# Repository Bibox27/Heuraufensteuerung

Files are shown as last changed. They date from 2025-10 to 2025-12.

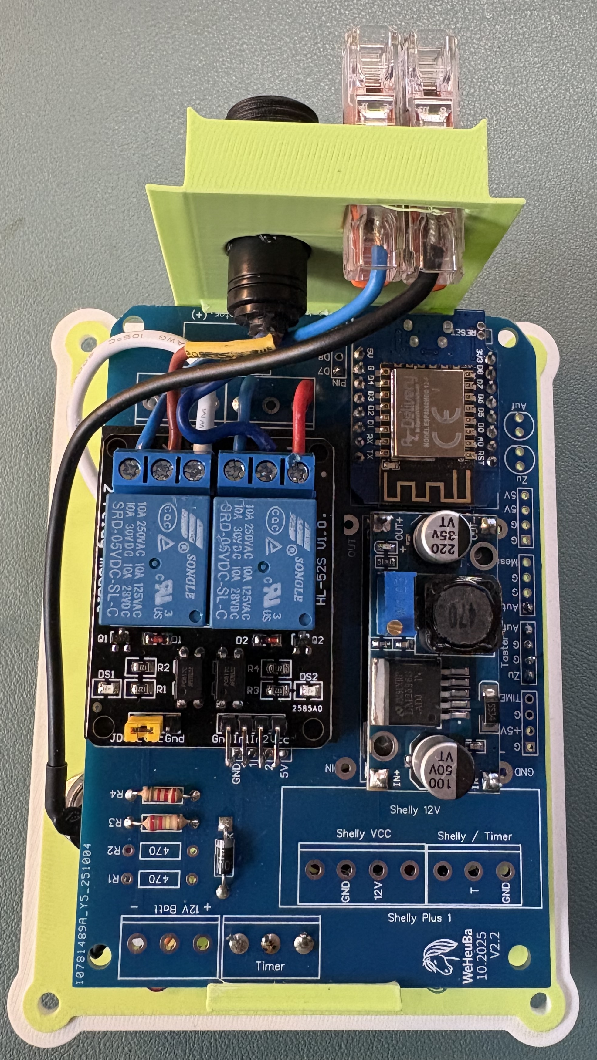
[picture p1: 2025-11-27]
Photos/IMG_0734.jpeg

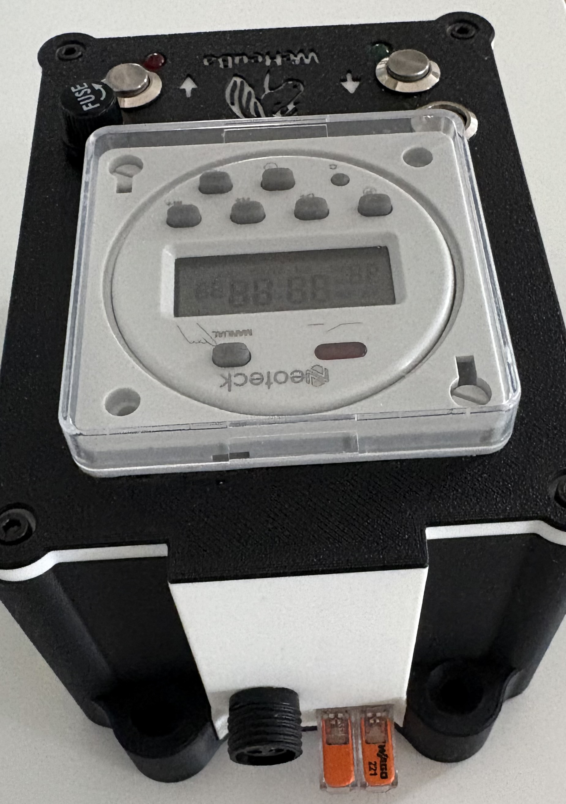
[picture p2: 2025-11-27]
Photos/IMG_0775.jpeg

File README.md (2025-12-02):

# Heuraufensteuerung
12V basierte Steuerung zum automatischen zeitabhängigem Öffnen und Schließen von Heuraufen

Bedienungsanleitung – ganz einfach erklärt
1. Grundprinzip
Die Steuerung bewegt einen Motor (12V DC) um eine Heuraufe zu öffnen oder zu schließen:
•	Öffnen (grüne LED)
•	Schließen (rote LED)
•	Entweder automatisch über die Zeitschaltuhr
•	Oder von Hand über die Taster
Die Fahrzeiten für Öffnen und Schließen sind fest einstellbar (webinterface)
 
2. Verhalten beim Einschalten (anlegen der 12V an die Steuerung)
Nach dem Start zeigt die Steuerung kurz:
1.	Grün leuchtet
2.	Rot leuchtet
Danach:
•	Wenn Auto-Modus AUS ist:
→ die rote LED blinkt (Hinweis: „Handbetrieb aktiv“)
 
3. Auto-Modus oder Handbetrieb
Auto-Modus EIN
•	Die rote LED blinkt nicht mehr
•	Die Zeitschaltuhr darf die Heuraufe automatisch bewegen
Handbetrieb
•	Rote LED blinkt dauerhaft
•	Die Zeitschaltuhr steuert NICHT, sie zeigt nur grün blinkend ein Signal an, wenn sie öffnen würde
•	Bewegen kann man nur über die beiden Taster
 
4. Taster „Auf“ (Öffnen)
Einfach drücken und halten
•	Motor fährt solange du drückst
•	Grüne LED leuchtet
•	Beim Loslassen → Motor stoppt sofort
Doppel-Klick (langsamer drücken als bei der Maus am Rechner)
•	Heuraufe öffnet komplett
•	Grüne LED leuchtet dabei
•	Danach stoppt alles wieder selbst
 
5. Taster „Zu“ (Schließen)
Einfach drücken und halten
•	Motor fährt solange du drückst
•	Rote LED leuchtet
•	Beim Loslassen → Motor stoppt sofort
Doppel-Klick (langsamer drücken als bei der Maus am Rechner)
•	Heuraufe schließt komplett
•	Rote LED leuchtet dabei
•	Danach stoppt alles wieder selbst
 
6. Zeitschaltuhr (Timer)
Der Timer kommt z. B. von einer Zeitschaltuhr oder einem Shelly Plus 1 12V (nicht installiert)
Wenn der Timer „an“ ist:
•	Die grüne LED blinkt
Im Auto-Modus zusätzlich:
•	Timer an → Die Heuraufe öffnet automatisch
•	Timer aus → Die Heuraufe schließt automatisch
Im Handbetrieb:
•	Die grüne LED blinkt nur als Anzeige
•	Die Heuraufe bewegt sich nicht automatisch
 
7. LED-Anzeigen – schnell erklärt
Grüne LED
•	Leuchtet: Die Heuraufe fährt auf
•	Blinkt: Timer aktiv
Rote LED
•	Leuchtet: Die Heuraufe fährt zu
•	Blinkt: Auto-Modus aus → Handbetrieb

Übersichtskarte – 6 Fresszeiten für deine Zeitschaltuhr
(ON = Öffnen / OFF = Schließen)

🕒 1. Beispiel-Fresszeiten 
Diese Zeiten sind alltagstauglich und orientieren sich an deinem Wunschstart um 06:00.
Fresszeit	Öffnen (ON)	Schließen (OFF)
1	06:00	07:00
2	10:00	11:00
3	13:00	14:00
… bis 20 Zeiten (meist reichen 5-6)
passe es genau an deinen Stall-Rhythmus an.
 
📘 2. Schritt-für-Schritt Anleitung zum Programmieren
🔧 A. Uhrzeit einstellen
1.	CLOCK gedrückt halten
2.	Währenddessen:
o	D+ = Wochentag
o	H+ = Stunde
o	M+ = Minute
3.	CLOCK loslassen → gespeichert
 
🟦 B. Schaltzeiten programmieren
Du programmierst immer ein Paar:
ON1 → OFF1, dann ON2 → OFF2 … bis ON6 → OFF6
 
🥇 Fresszeit 1 programmieren (06:00 – 07:00)
➤ ON1: Öffnen
1.	P drücken → Display zeigt 1 ON
2.	Wochentage mit D+ auswählen (am besten MO–SO)
3.	H+ → 06 einstellen
4.	M+ → 00 einstellen
➤ OFF1: Schließen
1.	P drücken → Display zeigt 1 OFF
2.	H+ → 07
3.	M+ → 00
 
🥈 Fresszeit 2 programmieren (10:00 – 11:00)
➤ ON2
•	P drücken, bis 2 ON erscheint
•	10:00 einstellen
➤ OFF2
•	P drücken, bis 2 OFF erscheint
•	11:00 einstellen
 
🥉 Fresszeit 3 programmieren (13:00 – 14:00)
➤ ON3
•	3 ON → 13:00
➤ OFF3
•	3 OFF → 14:00
 
🟩 Fresszeit 4 …
 
🔁 3. Wichtig: Betriebsmodus einstellen
Oben rechts der Schalter:
•	AUTO → das Programm läuft automatisch (muss aktiv sein)
•	ON → dauerhaft EIN
•	OFF → dauerhaft AUS
👉 Für die Heuraufe immer AUTO verwenden!

Technischer Hinweis:
Bei der beschriebenen Heuraufensteuerung handelt es sich um ein individuelles DIY-Projekt. Der Nachbau erfolgt vollständig auf eigene Verantwortung. Alle mechanischen, elektrischen und softwareseitigen Komponenten müssen vor Inbetriebnahme eigenständig geprüft, korrekt dimensioniert und sicher installiert werden. Für Schäden, Fehlfunktionen oder Risiken, die aus dem Nachbau oder unsachgemäßer Nutzung entstehen könnten, wird keinerlei Haftung übernommen. Jede Anpassung oder Erweiterung sollte nur mit entsprechendem Fachwissen durchgeführt werden.

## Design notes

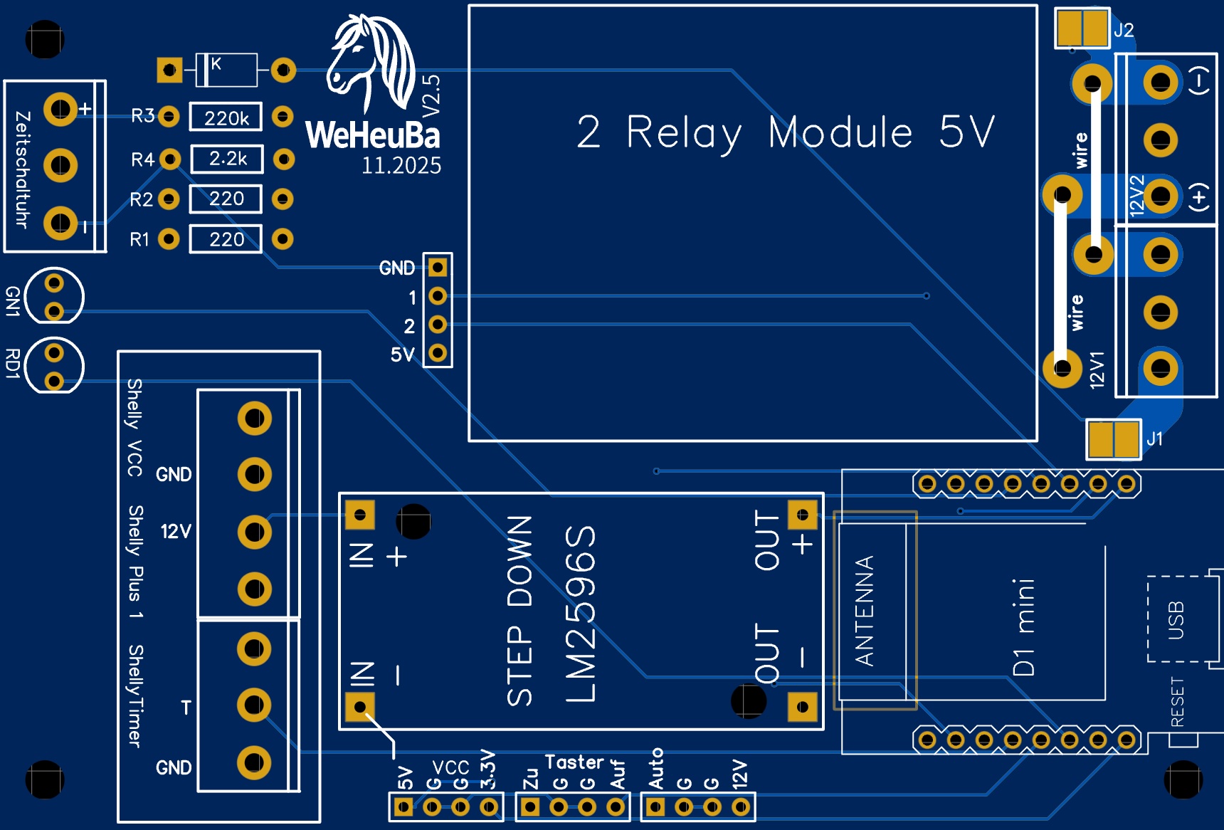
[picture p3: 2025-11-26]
Schematic/PCB Layout.jpg

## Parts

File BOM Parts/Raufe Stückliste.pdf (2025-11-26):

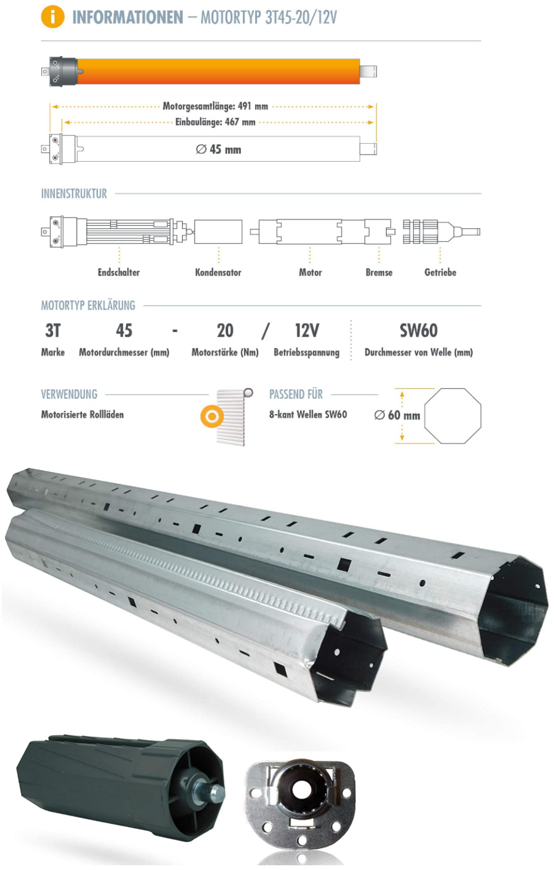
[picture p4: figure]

# Jalousiemotor mit Welle und Gurtscheiben

Preise auf Amazon (Februar 2023)
- 3T Rolladenmotor 12V 20Nm (40kg Zugkraft) | 100,90 €
- Achtkantwelle SW 60 150-170cm inkl. Lager | 26,90 €
- Gurtscheiben 4 x | 10,00 €
- Paracourt Seil 30m | 10,95 €
- Alurohr 4 x (20mm x 2 mm 2000mm lang) | 48,60 €
- Rohrverbinder (3D Drucker) habe ich auf thingivers.com hochgeladen
- Kabelbinder
- Windschutznetz | 22,95 €
- Umlenkrollen | 21,99 €
_______________________________________________________
| 242,29 €

# Automatische Heuraufe – Netz

Außenliegendes Gestänge, dass an den Raufenstützen hochgezogen wird. Das Netz rafft sich nach oben hin zusammen. Das Raffen kommt zustande indem das Paraourt Seil in 15 - 20 cm Abständen durch das Netz gezogen wird. Wer möchte kann mit Umlenkrollen alle vier Seiten mit dem Seil verbinden. Das hat den Vorteil, dass das Gestänge auch noch hochgezogen wird wenn ein Rohr aus den Eckenverbinden rausgezogen wurde (Pferd, Wind zerren daran).

Stand: Februar 2023

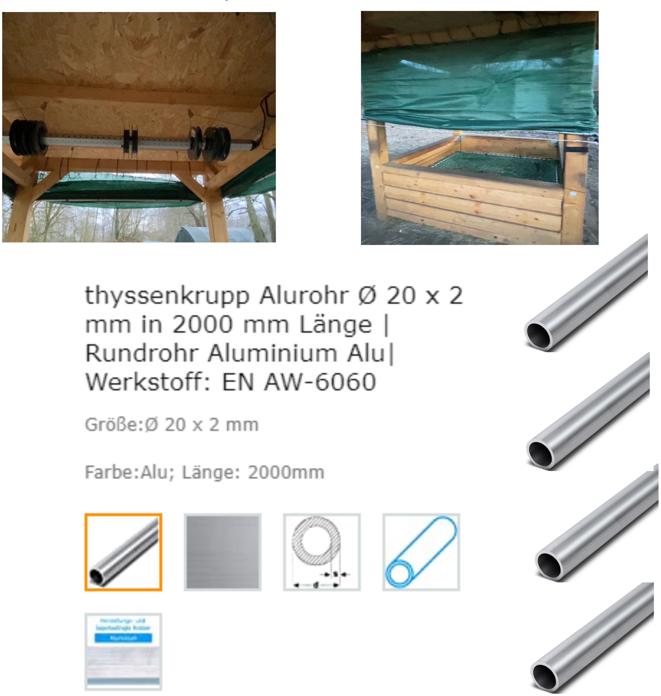
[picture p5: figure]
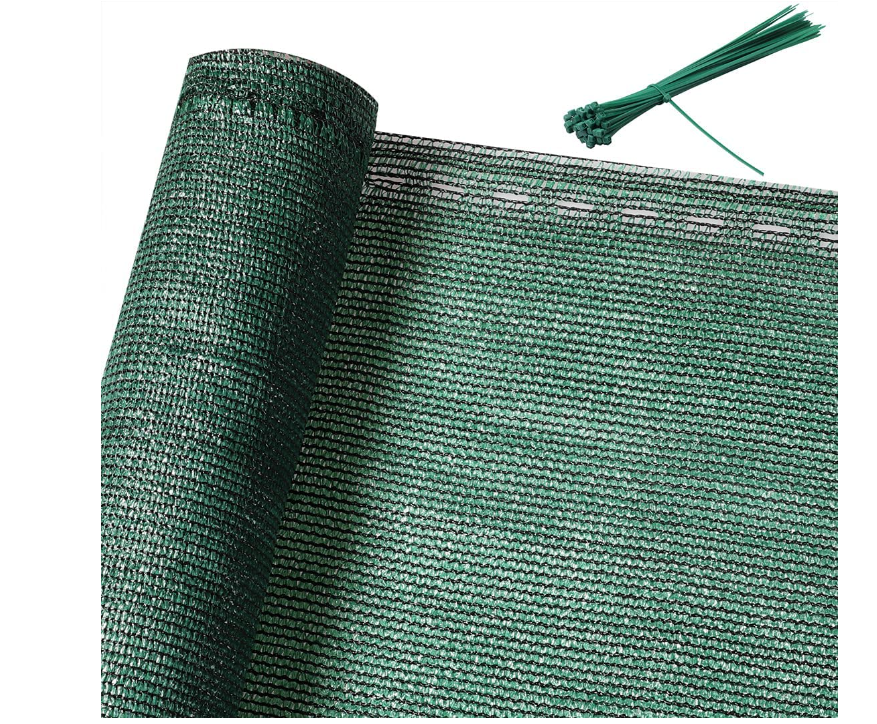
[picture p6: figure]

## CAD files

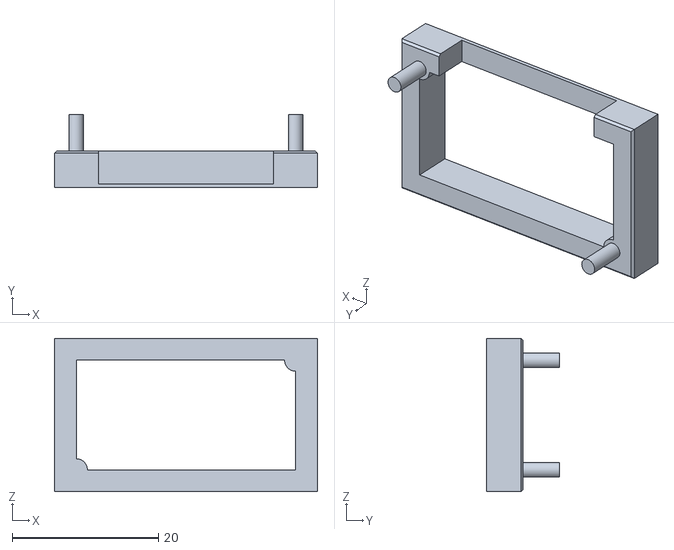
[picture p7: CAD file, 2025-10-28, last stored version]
LM2596_Halterung.stl
36.0 x 10.0 x 21.0

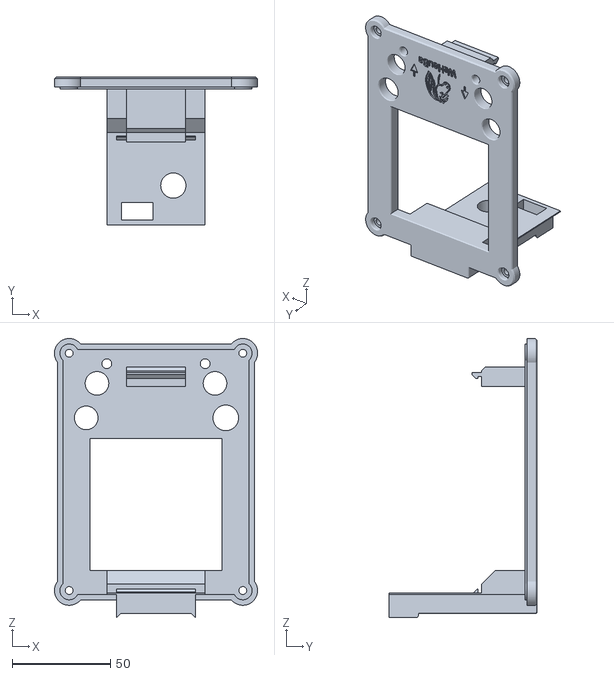
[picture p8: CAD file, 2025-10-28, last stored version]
WeHeuBa_Top (1).stl
103.3 x 75.0 x 141.8

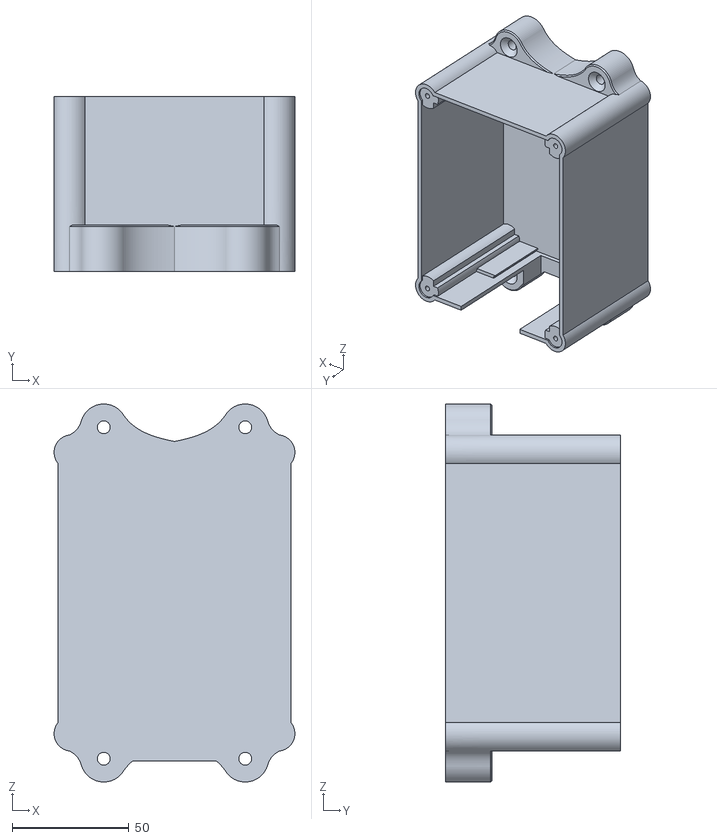
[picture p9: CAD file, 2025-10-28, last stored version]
WeHeuBa_Botton.stl
103.3 x 75.0 x 162.1

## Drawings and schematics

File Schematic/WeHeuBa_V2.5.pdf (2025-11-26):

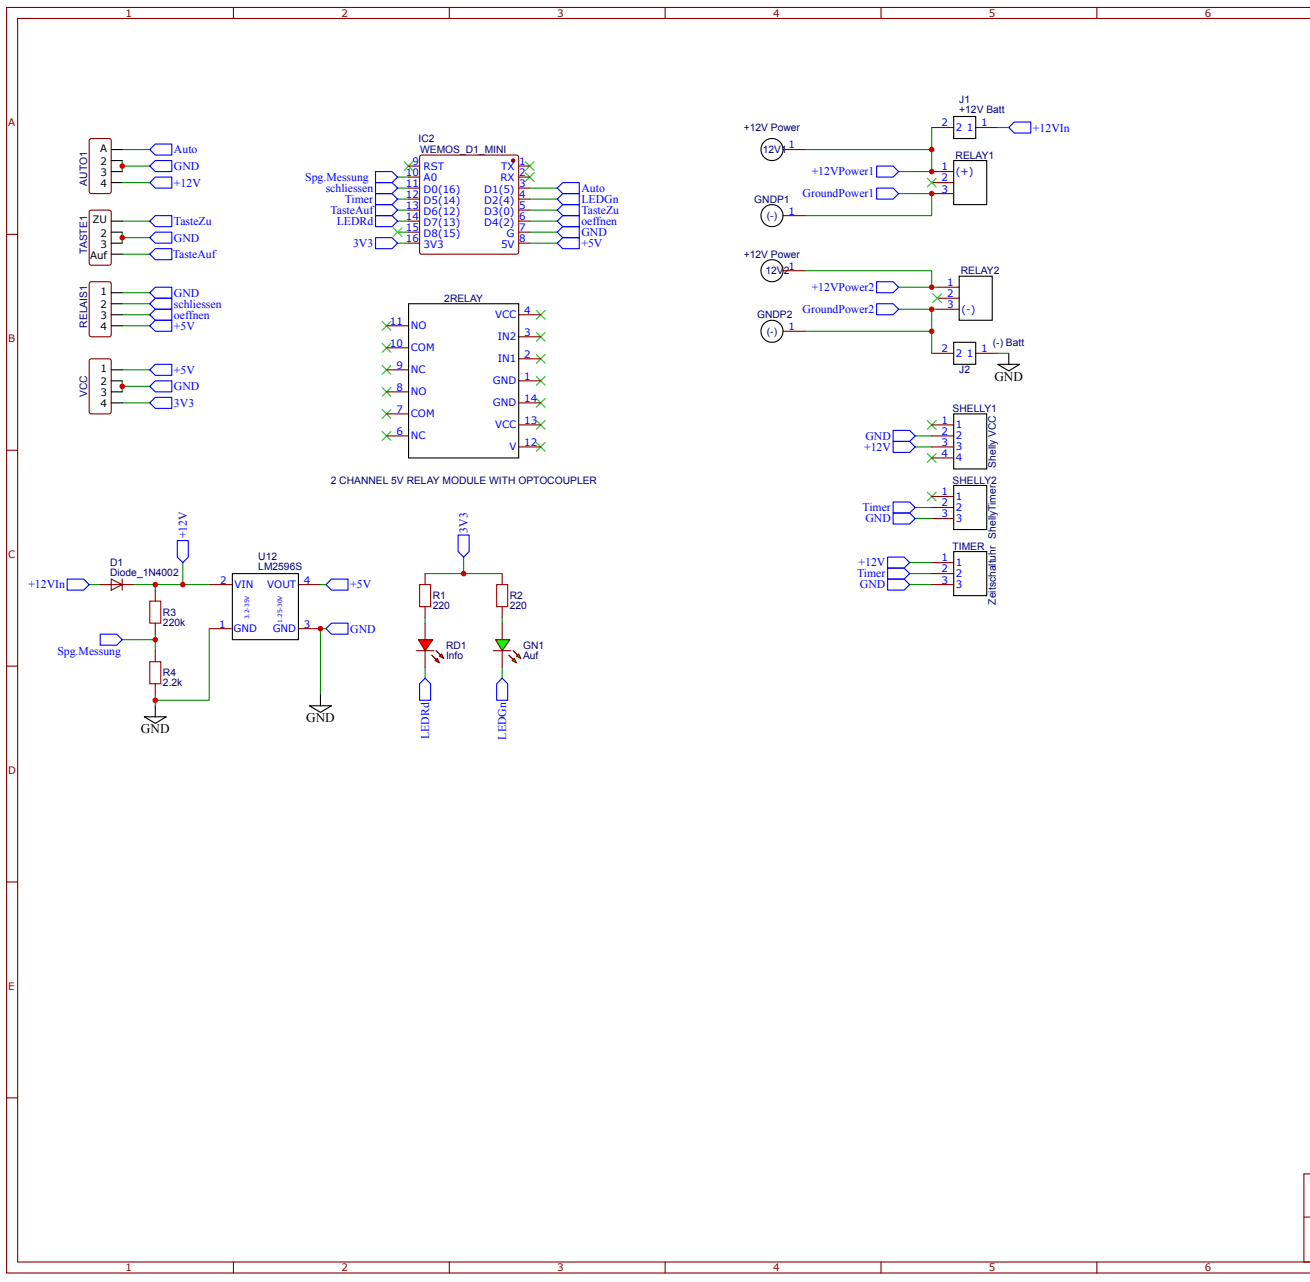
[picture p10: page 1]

2 CHANNEL 5V RELAY MODULE WITH OPTOCOUPLER
